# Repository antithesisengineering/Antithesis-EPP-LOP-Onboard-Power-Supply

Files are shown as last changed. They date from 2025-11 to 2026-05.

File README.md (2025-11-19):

# Antithesis EPP/LOP Onboard Power Supply

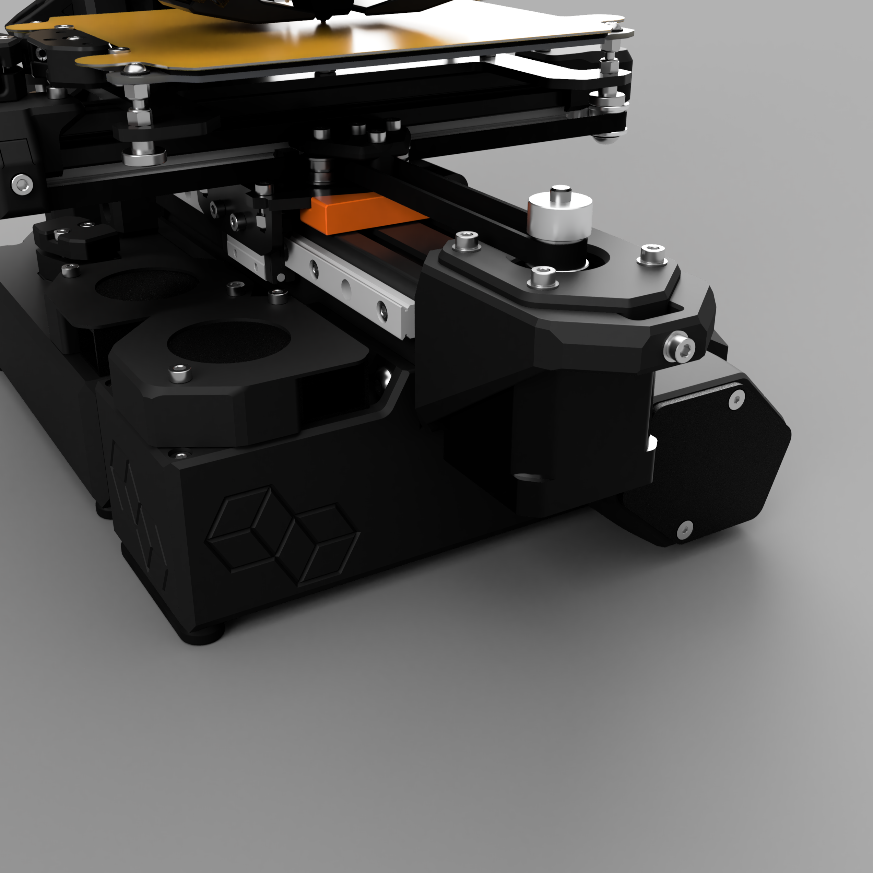
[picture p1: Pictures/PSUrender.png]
printer pic


## Description 
An onboard power supply compatible with all Antithesis printers which serves as a far more convenient, compact, and portable solution when compared to the external supply. It replaces the front foot assembly and can either route a cable through the side of the MCU enclosure or less ideally to the XT60 connector on the side. It can use either the 200W or 300W 24V EPP or LOP series of power supply. The LOP series is newer and slightly more compact but both supplies are often in short supply so obtain whichever one you can. I would consider the cooling fan to be mandatory. There are three options for powering it. Power it using a lead attacked to one of the 24V outputs, a spare fan port on your mainboard routing the fan cable back into the power supply, or via the fan connector on the PSU itself. However, you will need a 12V fan and an additional connector for that option. As it stands there are no assembly instructions but I will provide some pictures, the CAD, and a BOM complete with links for the harder to find stuff. 

## Max output
It is worth noting that the EPP and LOP are only rated for their maximum output with a 10CFM fan. As the 5015 provides approximately 30-50% of that, the maximum constant output will likely be prorated somewhat. The supply has been tested at a max constant output of 180W for 8 hours using a EPP-200-24 and a 5.5CFM 5015 fan. It performed well and didn't fault out during the test. This likely isn't a concern as that is equivalent to running both heaters at maximum for 8 hours straight. An unrealistic scenario that if real would present far bigger concerns than a melting PSU. Realistically the printer draws about 75W while printing.

## Disclaimer
WARNING: This project involves working with live high-voltage AC, which can cause serious injury, fire, or death if handled improperly. By using the information and/or design files in this repository, you acknowledge and accept full responsibility for your own safety. You are also responsible for compliance with all applicable local electrical codes, regulations, and safety standards.

You must disconnect all power sources and ensure that all capacitors or components capable of storing energy are fully discharged before opening, servicing, or modifying any part of the power supply.

The author(s) assume no responsibility or liability for any injury, damage, or consequences resulting from the use or misuse of this project.

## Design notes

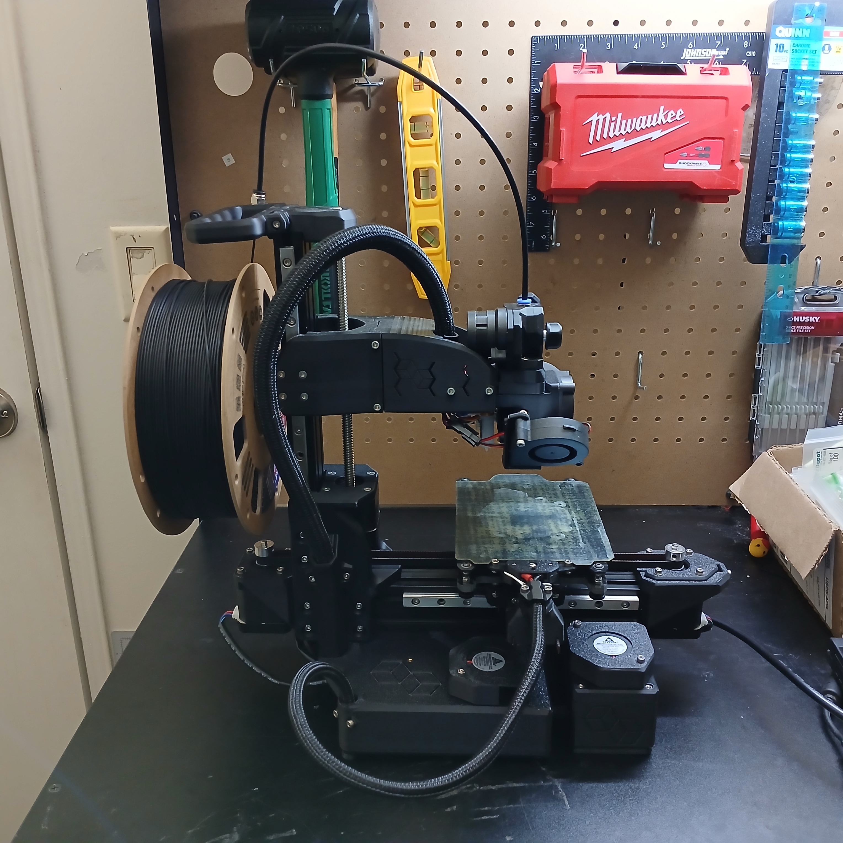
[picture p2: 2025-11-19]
Pictures/Through the side of the MCU Case.jpg

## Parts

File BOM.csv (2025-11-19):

EPP/LOP Onboard Power Supply BOM
 | Hardware
 |  | M3x8 SHCS | 8
 |  | M3x10 SHCS | 3
 |  | M3x20 SHCS | 2
 |  | M3x10 CS | 2 | Countersunk
 |  | M5x10 BHCS | 4
 |  | M5 Stamped T-Nut | 4
 |  | M3x5x4 Heat Set Insert | 11
 | Components
 |  | 24V EPP or LOP Power Supply | 1 | I would advise getting the LOP power supply unless you already have a EPP series on hand. The LOP is newer, smaller, and the 300W LOP is the same price as a 200W EPP. Either the 200W or 300W one will work fine. | https://www.digikey.com/en/products/detail/mean-well-usa-inc/epp-200-24/7703124 | https://www.digikey.com/en/products/detail/mean-well-usa-inc/LOP-200-24/22040939 | https://www.digikey.com/en/products/detail/mean-well-usa-inc/LOP-300-24/22040910
 |  | VHR-3N | 1 | 3 Pin Connector for the AC in. These are a little hard to find | https://www.digikey.com/en/products/detail/jst-sales-america-inc/VHR-3N/608625
 |  | VHR-6N | 1 | 6 Pin Connector for the DC out. These are a little hard to find | https://www.digikey.com/en/products/detail/jst-sales-america-inc/VHR-6N/608628
 |  | SVH-41T-P1.1 | 4 | Crimped contacts for the 18 AWG AC in and 16 AWG DC out wires. You should probably buy a few extra. | https://www.digikey.com/en/products/detail/jst-sales-america-inc/SVH-41T-P1-1/608760
 |  | SVH-21T-P1.1 | 2 | Crimped contacts for the 22 AWG JST lead for the cooling fan. Optional if you decide to power the fan from the MCU board. You should probably buy a few extra. | https://www.digikey.com/en/products/detail/jst-sales-america-inc/SVH-21T-P1-1/527368
 |  | JST-XH 2.54mm Plug Lead | 1 | Used to connect the fan to the 24V DC out. Needs to be 22 AWG. Optional if you decide to power the fan from the MCU board. | https://www.amazon.com/dp/B096DSGJLD?th=1
 |  | C14 Inlet with Switch | 1 | The important thing is to make sure its the correct style as seen in the instructions and link. | https://www.amazon.com/dp/B0BCYYNRGP?th=1
 |  | C13 Power Cord | 1 | Buy which ever length you need. | https://www.amazon.com/Standard-Electronics-Computer-Printer-Monitor/dp/B09VRLJD7J/ref=1
 |  | 5015 24V Blower Fan | 1 | Should be 24V unless you plan to power it off the PSU boards specific fan connector in which case you will need 12V. | https://www.amazon.com/GDSTIME-Cooling-Brushless-Hydraulic-Humidifier/dp/B0DLKNMH5R/ref=1
 |  | 2.5mm(.1in) Wide Zip Tie | 1
 |  | 16 AWG Wire |  | Cut to length for 24V DC out. While the amount needed varies 175mm(7in) Should be enough for most setups.
 |  | 6mm(1/4in) Split Cable Sleeve 25mm(1in) |  | This is for the gap between the PSU and MCU enclosures.

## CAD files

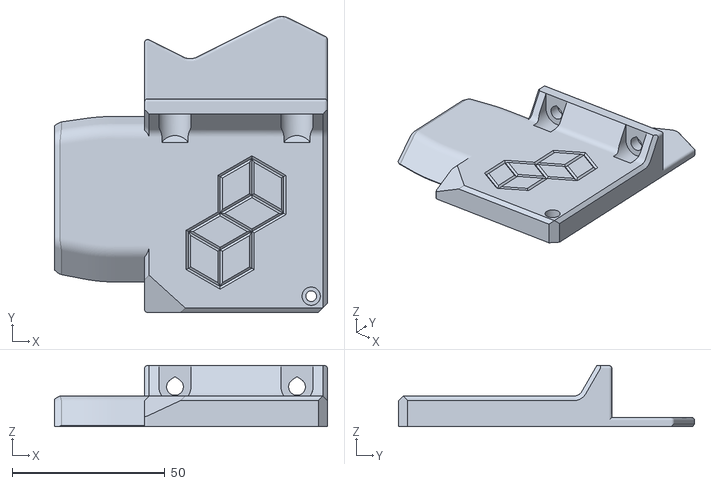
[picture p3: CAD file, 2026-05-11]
STLs/PSU_Case_3_x1.stl
89.5 x 97.0 x 20.0

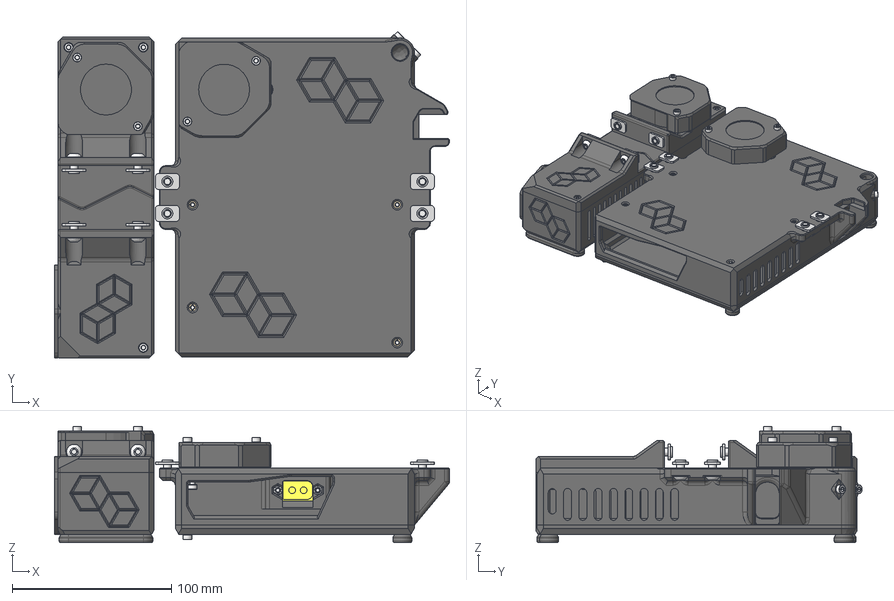
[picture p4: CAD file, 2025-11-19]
CAD/Antithesis EPP&LOP Onboard PSU v4.step
247.8 x 204.8 x 73.0 mm
M3x10 SHCS x 9
Stabilizer Foot (Printed TPU) x 2
Bed Cable Clamp
Enclosure Main Cable Clamp
M3x8 SHCS x 10
M3x20 SHCS x 8
M3x5x4 Heat Set Insert x 25
5015 Blower Fan Mockup x 2
XT60E-F Mockup
M3x10 CS x 4
M3 Nylon Insert Nut x 2
Manta M5P Enclosure Lid
5015 Fan Shroud x 2
M5 Stamped T-Nut x 8
M5x10 BHCS x 8
EPP/LOP Mockup
PSU Foot (EPP/LOP) (Printed TPU) x 2
PSU Standoffs
DC Out Plug
C14 Inlet Mockup
PCU Case (EPP/LOP) 3
PSU Case (EPP/LOP)
PSU Case (EPP/LOP) 2

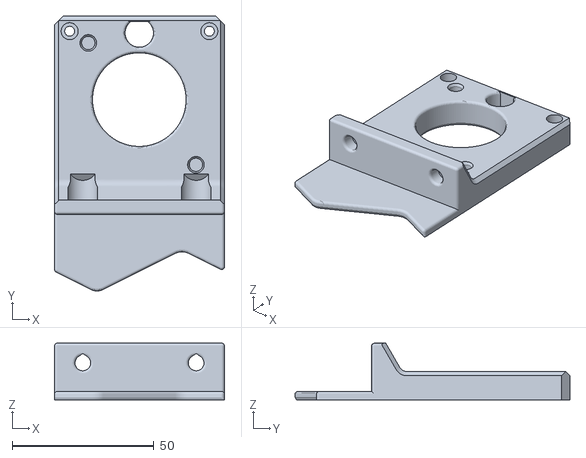
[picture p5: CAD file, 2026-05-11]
STLs/PSU_Case_2_x1.stl
60.0 x 97.0 x 20.0

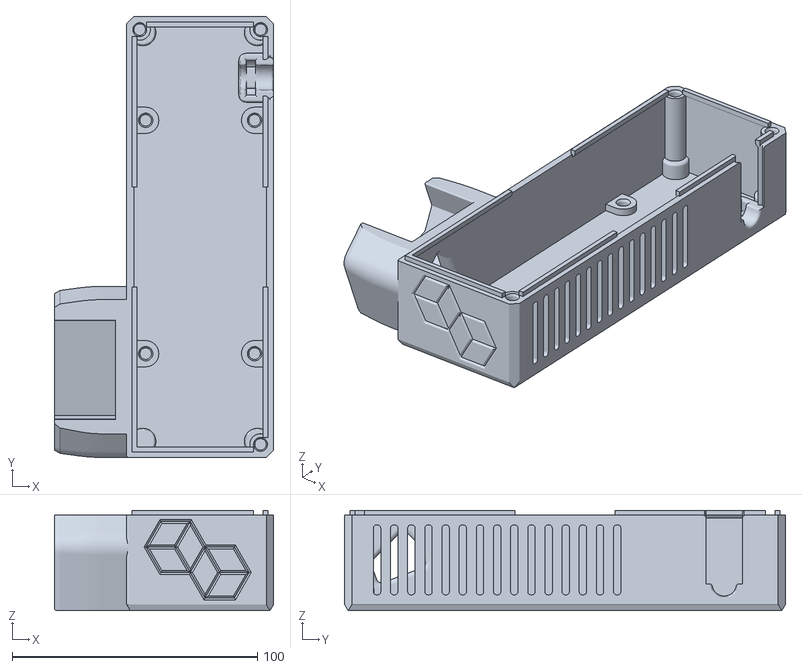
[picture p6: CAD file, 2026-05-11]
STLs/PSU_Case_1_x1.stl
89.5 x 180.0 x 41.0

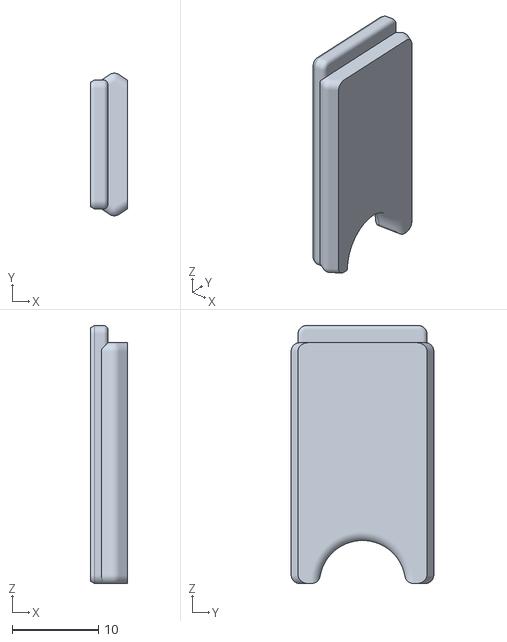
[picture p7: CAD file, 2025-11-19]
STLs/DC Out Plug_x1.stl
4.25 x 16.6 x 30.0

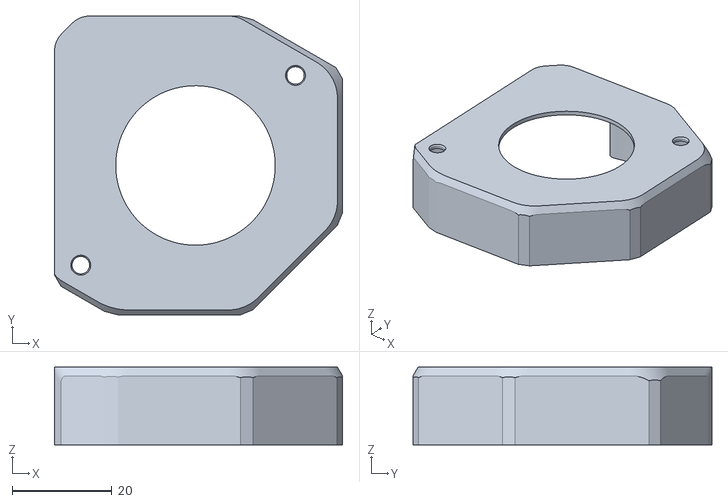
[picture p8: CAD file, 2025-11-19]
STLs/5015 Fan Shroud_x1.stl
57.8 x 60.0 x 15.6

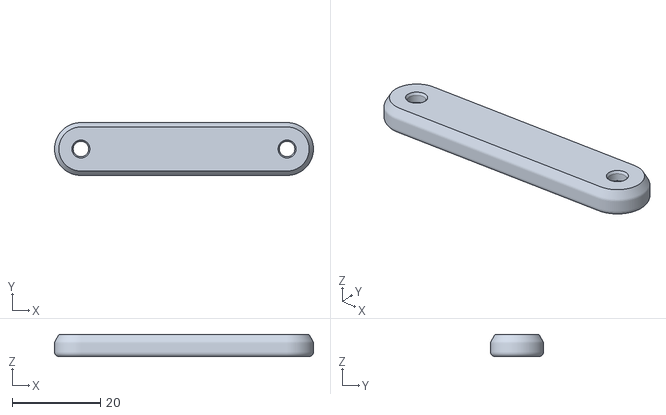
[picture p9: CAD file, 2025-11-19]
STLs/PSU_Foot_(TPU)_x2.stl
58.8 x 12.0 x 5.00

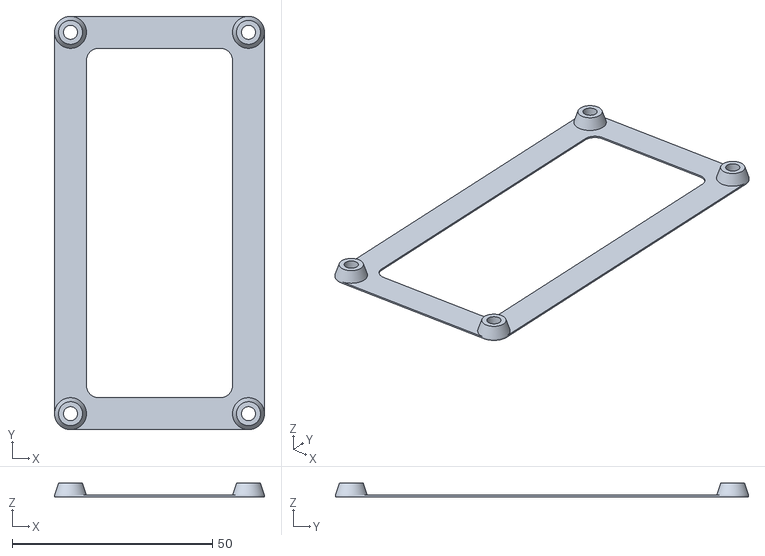
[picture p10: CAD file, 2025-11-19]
STLs/PSU_Standoffs_x1.stl
52.5 x 103.2 x 3.40

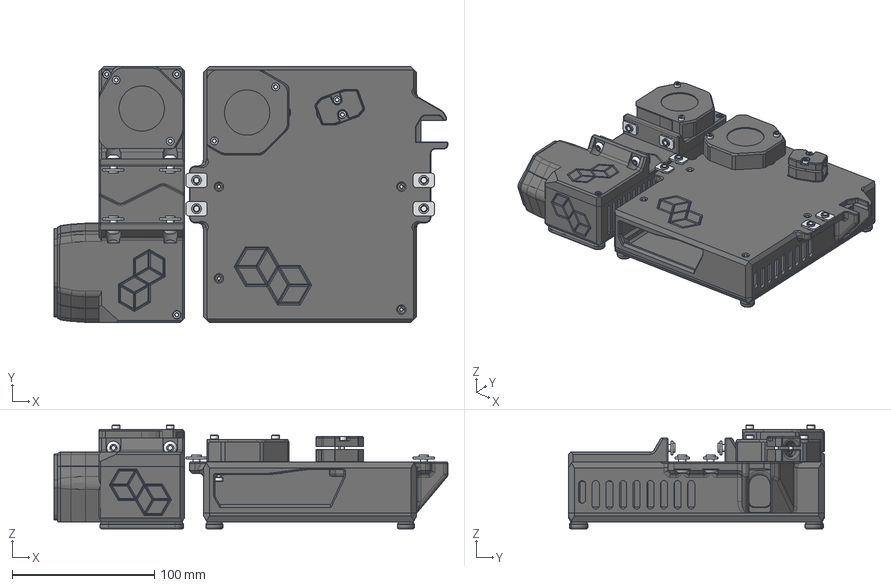
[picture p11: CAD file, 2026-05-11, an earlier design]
CAD/Antithesis EPP&LOP Onboard PSU v2.step
277.3 x 180.0 x 73.0 mm
Stabilizer Foot (Printed TPU) x 4
Enclosure Main Cable Clamp
Manta M5P Enclosure Lid
5015 Fan Shroud x 2
Manta M5P Enclosure (Onboard PSU only)
Bed Cable Clamp Bottom Enclosure
Bed Cable Clamp Top Enclosure
M3x10 SHCS x 11
M3x20 SHCS x 8
M3x5x4 Heat Set Insert x 25
5015 Blower Fan Mockup x 2
M5 Stamped T-Nut x 8
M5x10 BHCS x 8
EPP/LOP Mockup
PSU Foot (EPP/LOP) (Printed TPU) x 2
PSU Standoffs
DC Out Plug
C14 Inlet Mockup
PCU Case (EPP/LOP) 3
PSU Case (EPP/LOP)
PSU Case (EPP/LOP) 2
M3x8 SHCS x 8
M3x10 CS x 2

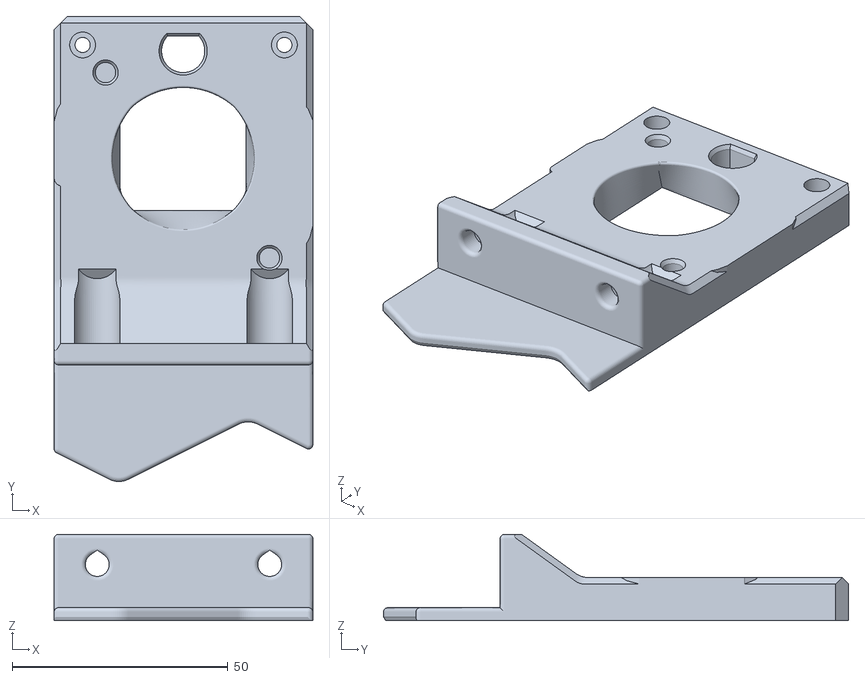
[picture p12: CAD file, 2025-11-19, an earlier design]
Previous Versions/V1/STLs/PSU_Case_2_x1.stl
60.0 x 107.8 x 20.0

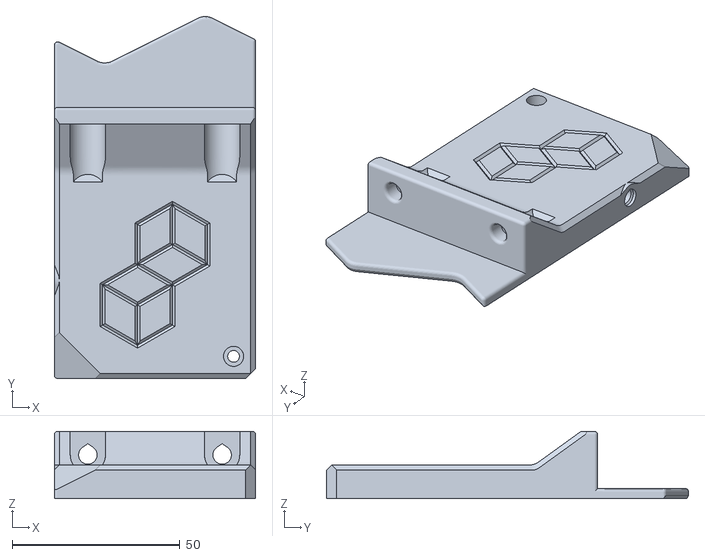
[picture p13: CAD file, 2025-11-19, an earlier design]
Previous Versions/V1/STLs/PSU_Case_3_x1.stl
60.0 x 107.8 x 20.0

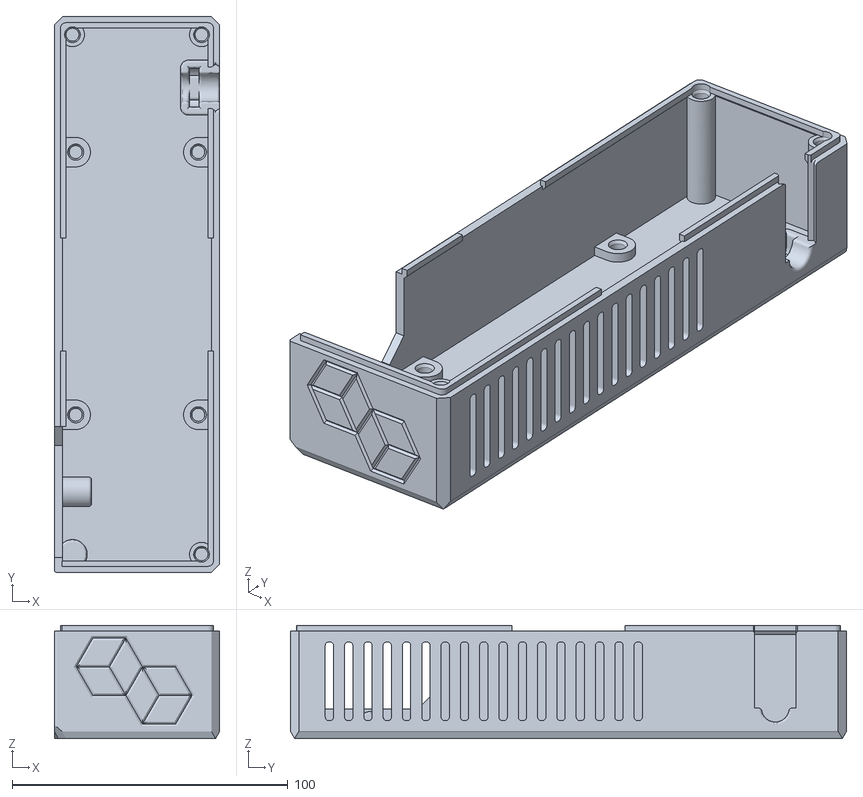
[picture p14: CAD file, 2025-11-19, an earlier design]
Previous Versions/V1/STLs/PSU_Case_1_x1.stl
60.0 x 201.6 x 41.0

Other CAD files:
Previous Versions/V1/CAD/Antithesis EPP&LOP Onboard PSU v1.step
CAD/Antithesis EPP&LOP Onboard PSU v2.f3d
CAD/Antithesis EPP&LOP Onboard PSU v4.f3d
Previous Versions/V1/CAD/Antithesis EPP&LOP Onboard PSU v1.f3d
